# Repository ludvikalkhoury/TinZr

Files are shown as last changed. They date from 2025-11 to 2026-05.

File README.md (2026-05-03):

# TinZr ESP32-C3 Arduino Board Manager Package

This repository contains the **TinZr**, an ESP32-C3-based custom board definition for the Arduino IDE.  
It provides a clean, Boards-Manager-installable package so anyone can use your board with one simple URL.

## Publication Status
The manuscript describing this work is currently under peer review.
The materials in this repository correspond to the submitted version of the work.
Please refrain from redistributing or reproducing this work until the peer-review process is complete.
In the meantime, the preprint is available on SSRN: https://ssrn.com/abstract=6380099, and is also included in this repository (`TinZr_PrePrint_2026-03-30.pdf`). 

If you use this work, please cite:
> **Alkhoury, Ludvik** and Moore, Tony and Swissler, Petras and Hill, Jeremy and Shah, Sudhin A. and Kam, Moshe, TinZr: A Compact Wireless ESP32-C3 Platform for Multi-modal Physiological Data Acquisition (January 01, 2026). Available at SSRN: http://dx.doi.org/10.2139/ssrn.6380099 

---
## Pinout
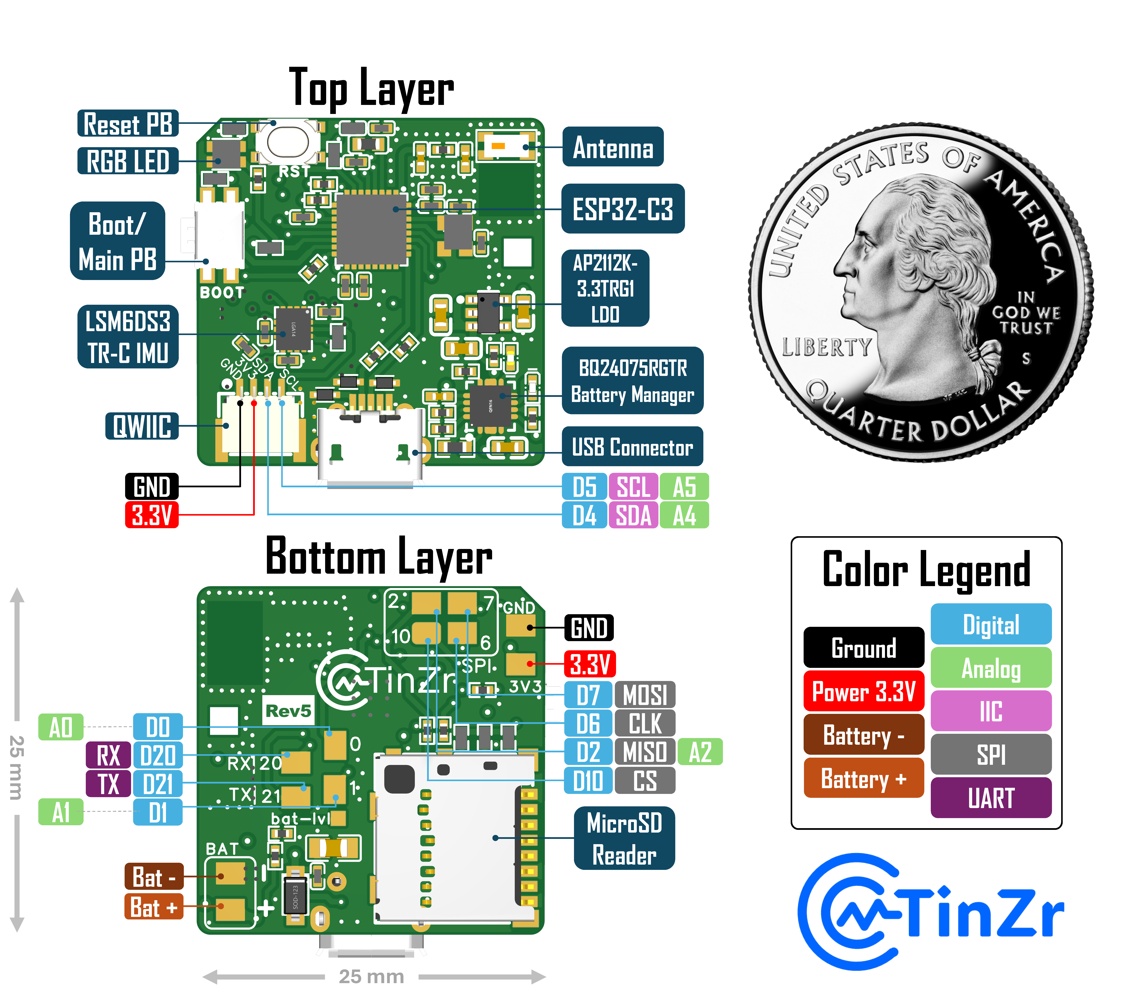
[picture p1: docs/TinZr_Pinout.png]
TinZr ESP32-C3 Pinout


## 🚀 Quick Install

### 1️⃣ Install Espressif ESP32
Open the Arduino IDE and go to:
- Go to **Tools → Board → Boards Manager**
- Find ``esp32 by Espressif Systems``
- Install *only* version `3.3.4`

**⚠️ IMPORTANT: This project is tested and supported exclusively with ESP32 core version `3.3.4`.**  
**Do NOT use any other version — builds may fail or behave incorrectly.**

### 2️⃣ Add the Boards Manager URL
Open the Arduino IDE and go to:

**File → Preferences → Additional Boards Manager URLs**, then paste:

```
https://ludvikalkhoury.github.io/TinZr/package_tinzr_index.json
```

Click **OK**.

### 3️⃣ Install the board package
In Arduino IDE:
- Go to **Tools → Board → Boards Manager**
- Search for **TinZr**
- Click **Install**

### 4️⃣ Select your board
Go to:

**Tools → Board → TinZr Boards → TinZr ESP32-C3 Rev5**

### 5️⃣ Install `TinZrConnect` as a Zipped Arduino Library
#### A) Create the ZIP (IMPORTANT: zip the *library folder*, not the whole TinZr repo)
- Navigate to the `libraries` directory. There you will find the `TinZrConnect` folder (the one that contains `library.properties`).
- Create a zipped version of the `TinZrConnect` folder, and name it `TinZrConnect.zip`.

#### B) Install the ZIP in Arduino IDE
1. In Arduino IDE, go to:
   - **Sketch → Include Library → Add .ZIP Library…**
2. Select `TinZrConnect.zip`
3. Wait for the confirmation message (bottom status bar).

#### C) Verify Installation
1. Go to:
   - **File → Examples**
2. Scroll to find:
   - **TinZrConnect**
3. Open an example sketch and compile.

If you see the examples and the sketch compiles, the library is installed correctly ✅

## 💡 Example Sketch (NeoPixel Test)

```cpp
#include <Arduino.h>
#include "TinZrCore.h" // this library declares TinZrCore TinZr
#include "TinZrLED.h"  // this library declares TinZrStatusLED TinZrLED

void setup() {
    TinZr.begin(25); //LED brightness is 25
}

void loop() {
    TinZrLED.setColor(255,0,0); delay(500);
    TinZrLED.setColor(0,255,0); delay(500);
    TinZrLED.setColor(0,0,255); delay(500);
}
```

#

Copyright © 2026 Ludvik Alkhoury

This software is licensed under the GNU General Public License v3.0.
Commercial licensing options are available upon request.

OSHW Facts

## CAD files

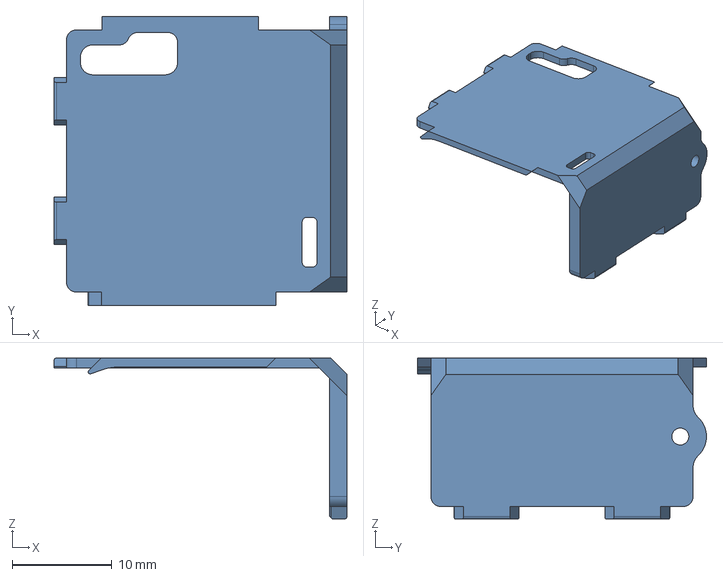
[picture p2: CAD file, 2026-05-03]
3D_designs/TinZrWearableEnclosure - Lid.step
29.4 x 29.0 x 16.2 mm

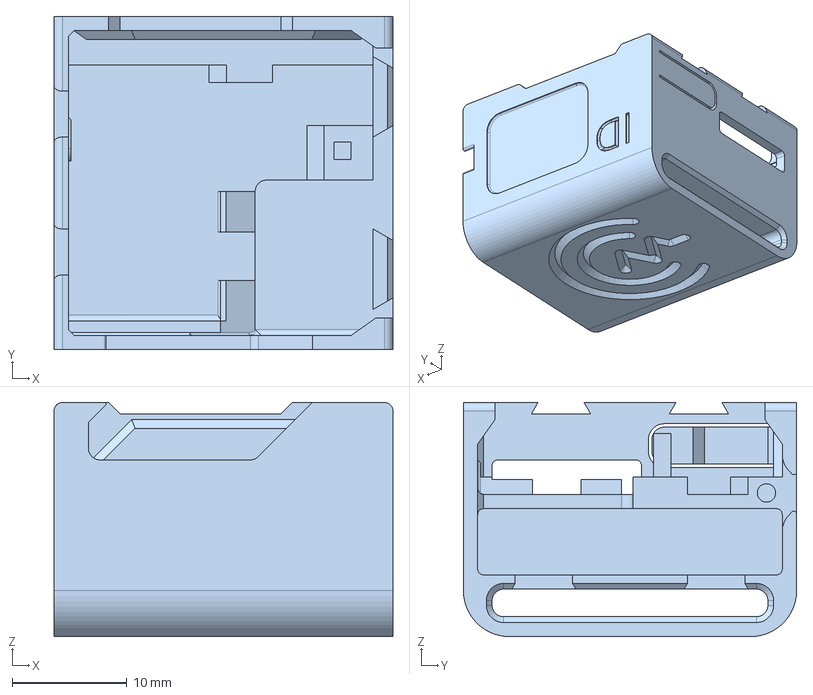
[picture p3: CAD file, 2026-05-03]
3D_designs/TinZrWearableEnclosure - Body.step
29.5 x 29.0 x 20.4 mm

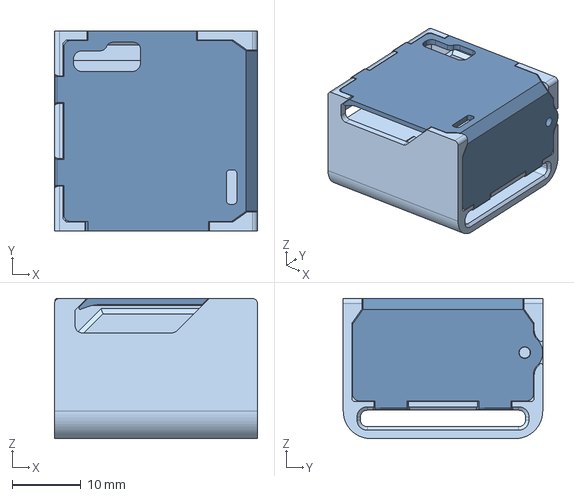
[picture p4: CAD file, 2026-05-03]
3D_designs/TinZrWearableEnclosure.step
29.5 x 29.0 x 20.4 mm

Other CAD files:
3D_designs/TinZrWearableEnclosure - Body.stl
3D_designs/TinZrWearableEnclosure - Lid.stl

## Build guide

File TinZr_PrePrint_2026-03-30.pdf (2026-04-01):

# PREPRINT

PRE-PRINT – this manuscript has not undergone peer review. It is provided for reading and discussion purposes only.

© 2026 Ludvik Alkhoury. All rights reserved. This preprint is made available on arXiv under the arXiv.org perpetual, non-exclusive license.

Article title
TinZr: A Compact Wireless ESP32-C3 Platform for Multi-modal Physiological Data Acquisition.

Authors
Ludvik Alkhoury ¹,∗
, Tony Moore ²

, Petras Swissler ³

, N. Jeremy Hill ⁴,5
, Sudhin A. Shah ¹

, and Moshe Kam⁶,∗

Affiliations
1 Department of Radiology, Weill Cornell Medicine, New York, NY, 10065 USA
2 Mortronics Limited, Folkstown, Balbriggan, Dublin, Ireland
3 Mechanical Engineering Department, New Jersey Institute of Technology, Newark, NJ, USA
4 National Center for Adaptive Neurotechnologies, Stratton VA Medical Center, Albany, NY, USA
5 Electrical and Computer Engineering Department, State University of New York at Albany, NY, USA
6 Electrical and Computer Engineering Department, New Jersey Institute of Technology, Newark, NJ, USA Corresponding authors email addresses
∗Ludvik.alkhoury@gmail.com and Kam@njit.edu

Abstract
Microcontrollers have become central to wearable technologies. As these systems continue to evolve, both form factor and functional integration have become critical design considerations. In this study, we present TinZr, a compact, wireless, and open-source controller based on the ESP32-C3 microcontroller. The TinZr integrates an inertial measurement unit (IMU), an onboard battery management circuit, Wi-Fi and Bluetooth Low Energy, a microSD card reader, and multiple GPIOs supporting digital, analog, I²C, SPI, and UART interfaces. The complete system measures only 25 mm × 25 mm, making it well-suited for wearable applications. All production files, including PCB design, firmware, and a 3D model of a wearable enclosure, are publicly available. Two primary use cases for TinZr are demonstrated: (a) multi-device communication and coordination, and (b) wireless IMU data acquisition. The TinZr supports both real-time data streaming via Wi-Fi/BLE and local logging to a microSD card. Local streaming makes the TinZr suitable for extended research experiments and field studies where continuous wireless connectivity may not be available. An accompanying Arduino library, TinZrConnect, is provided to facilitate programming and integration with existing systems. Overall, the combination of compact design, wireless flexibility, and open-source accessibility, makes TinZr a versatile solution for various sensing applications.

Keywords
Microcontroller, ESP32-C3, Wearable Devices, Physiological Signals, Physiological Monitoring, Data Acquisition, Multimodal Signals, Wireless Communication, Multi-Device Synchronization, Open-Source Hardware, Signal Processing, Inertial Measurement Unit (IMU), Low-Power Design, MicroSD Data Logging, Battery-Powered Systems

# PREPRINT

### 1. Specifications table

Hardware name | TinZr
Subject area | • Electrical and biomedical engineering • Neuroscience • Swarm robotics • Educational tools and open source alternatives to existing infrastructure
Hardware type | • Measuring physical properties and in-lab sensors • Field measurements and sensors • Electrical and biomedical engineering • Multi-functional microcontroller platform • Compact and wearable embedded controller • Wireless data acquisition and communication system (Wi-Fi / BLE) • Real-time signal processing • Physiological signal acquisition and sensor interfacing (ECG, PPG, IMU) • Supports digital communication protocols (I²C, SPI, UART, GPIO)
Closest commercial analog | • Seeed XIAO ESP32-C3 • ESP32-C3 Mini • DFRobot Beetle ESP32-C6 • Adafruit GEMMA v2 • Teensy 4.1
Open source license | CERN Open Hardware Licence (OHL) v2.0 Permissive
Cost of hardware | $65 (including shipping and customs duties)
Source file repository | https://osf.io/hx4cm/
OSHWA certification UID | US002796

# PREPRINT

### 2. Hardware in context

Wearable sensing platforms are gaining popularity for their ability to deliver non-invasive, continuous health insights to athletes, patients, and everyday users – while evolving to incorporate sophisticated on-device sensors and analytics. The global wearable sensors market was valued in 2024 at USD 1.4 billion and is projected to grow to USD 6.3 billion by 2033, at a compound annual growth rate (CAGR) of 18.3% over 2025–2033 [1, 2]. This surge is largely driven by growing demand for telehealth, long-term monitoring, real-time health tracking, and military applications.
Physiological signal monitoring has become increasingly widespread, with wearable systems now employed by athletes, patients, soldiers, and everyday users to enable continuous health and performance tracking [3, 4, 5, 6]. Consequently, many everyday wearables (e.g., watches) now go beyond basic functionality by including onboard sensing hardware, such as accelerometers for activity and motion tracking [7]; photoplethysmography (PPG) sensors for heart rate [8] and oxygen saturation calculation [9]; electrocardiography (ECG) sensors for cardiac rhythm monitoring [10]; temperature sensors for body or skin thermal profiling [11]; and even biochemical sensors for measuring variables like glucose [12], for richer health and activity monitoring [4, 13].
Wearable systems for physiological monitoring increasingly depend on microcontroller units (MCU) and platforms that provide tight integration, compact form factors, and support for multi-modal sensing. The continued miniaturization and increasing computational capability of modern MCUs have made it possible to embed real-time sensing, processing, and wireless communication within small, battery-powered enclosures. Additionally, such MCUs offer sufficient local processing power, robust data logging, and versatile interfaces for auxiliary modules such as inertial, optical, and electrophysiological sensors.
Several open hardware and research platforms have emerged to address these challenges. For instance, Cog-Watch [14] is an open-source multi-sensor wrist platform that integrates heart rate, respiration, skin conductance, and temperature sensing, to study physiological and behavioral responses in daily activities. CogWatch uses the Adafruit QT Py ESP32-S2 MCU [15] for data acquisition and measures around 29 mm x 38 mm (just the PCB without any sensor enclosures). H-Watch [16] extends these capabilities into a wristwatch-like platform that incorporates multiple radios and energy harvesting, maintaining ultra-low power consumption for long-term wearable deployment. The main purpose of H-Watch is early COVID-19 detection. BioGAP-Ultra
[17] is a modular edge-AI platform that supports synchronized acquisition of EEG, EMG, ECG, and PPG signals with on-device processing and flexible form factors. The BioGAP-Ultra firmware runs on the nRF5340 SoC using the Zephyr RTOS, and the accompanying Android software suite enables background data reception, real-time visualization, some parameter configuration, and data storage. Finally, the Multi-Sensor Wearable Health Device (MWHD) framework [18] uses the CC2640R2F Cortex®-M3 [19] MCU for real-time heart rate and peripheral oxygen saturation (SpO2) monitoring from PPG signals, temperature, and motion, coupled with wireless data transmission and mobile application feedback. Together, these platforms illustrate the stateof-the-art in wearable microcontroller integration, where the convergence of low-power embedded processing, miniaturization, and open hardware design has enabled compact, reconfigurable, and affordable solutions for physiological signal monitoring.
Some of the above-mentioned platforms demand significant expertise to program or extend at the driver and firmware level. However, there are compact and flexible MCUs that can be easily programmed via the Arduino ecosystem – making them highly accessible for rapid prototyping, research deployments, and wearable device development. For example, we list several widely used controllers such as Seeed XIAO ESP32-C3 [20], DORHEA ESP32-C3 Mini [21], DFRobot Beetle ESP32-C6 [22], Adafruit GEMMA v2 [23], and PJRC Teensy 4.1 [24]. In general, most of these controllers are compact and thus suitable for wearable applications. The Seeed XIAO ESP32-C3 is very compact and offers Wi-Fi/BLE connectivity with onboard battery management, though it lacks a microSD card reader and has limited header accessibility. The DORHEA ESP32-C3 Mini does not include battery management or an SD card interface. The DFRobot Beetle ESP32-C6 similarly lacks an SD card reader and accessible headers. The Adafruit GEMMA v2 is extremely small and lightweight but does not include a charging unit, SD card reader, and expansion headers. The PJRC Teensy 4.1 includes an SD card reader, making it well-suited for data logging, but it lacks Wi-Fi/BLE and is physically bulkier than the other options.
In this study, we introduce the TinZr, which builds on existing designs by providing a fully wireless con-

# PREPRINT

troller in a compact 25 mm × 25 mm form factor, combining sensing, data logging, and communication in a minimal open-source package. It uses the ESP32-C3 MCU and integrates an inertial measurement unit (IMU) comprising a 3-axis accelerometer and 3-axis gyroscope, battery management circuitry, Wi-Fi and BLE 5.0 connectivity, a microSD card reader, and GPIOs supporting digital, analog, I²C (it provides an on-board QWIIC connector), SPI, and UART. A detailed specification comparison between the commercially available controllers and the TinZr is available in Table 1. Importantly, the TinZr can be programmed via the Arduino ecosystem, lowering the barrier to use. This functional density enables multimodal physiological signal acquisition, on-device processing, and flexible data handling (streaming or local logging). All production files for the TinZr, including PCB designs and 3D enclosure models for wearables applications, are publicly available at https://osf.io/hx4cm/. The onboard microSD reader supports long-duration, high-resolution logging, essential for field or extended experiments where continuous wireless transmission may not be feasible. Wireless connectivity via Wi-Fi and BLE remains available when real-time streaming is needed. We provide an accompanying Arduino library, TinZrConnect, to facilitate programming and integration of TinZr with existing systems. Overall, TinZr offers a low-cost, power-efficient, and compact alternative that surpasses lighter platforms by combining local storage, wireless flexibility, and standardized sensor interfacing in a single module.

| Seeed XIAO ESP32-C3 [20] | DORHEA ESP32-C3 Mini [21] | DFRobot Beetle ESP32-C6 [22] | Adafruit GEMMA v2 [23] | PJRC Teensy 4.1 [24] | TinZr
Dimensions (mm) | 21 x 17.8 | 22 x 18 | 25 x 20 | 28 (diameter) | 61 x 18 | 25 x 25
Nbr. GPIOs | 11 | 11 | 13 | 3 | 55 | 10
Nbr. Analog Pins | 4 | 4 | 7 | 1 | 18 | 5
Nbr. Digital Pins | 11 | 11 | 13 | 3 | 55 | 10
2C I | Yes | Yes | Yes | Yes | Yes | Yes
SPI | Yes | Yes | Yes | Yes | Yes | Yes
UART | Yes | Yes | Yes | No | Yes | Yes
On-board Mi-croSD Card Reader | No | No | No | No | Yes | Yes
On-board Bat-tery Management | Yes | No | Yes | No | No | Yes
On-board QWIIC Connector | No | No | No | No | No | Yes
On-board IMU | No | No | No | No | No | Yes
On-board Con-trollable RGB LED | No | No | No | No | Yes | Yes
On-board Push Button | Yes (Reset & Boot) | Yes (Reset & Boot) | Yes (Reset & Boot) | Yes (Reset) | Yes | Yes (Reset & Boot/Control)
Unit Price (in USD) (January, 2026) | ∼ $5 − 10 | ∼ $8 − 12 | ∼ $7 − 10 | ∼ $9.95 | ∼ $30 − 50 | ∼ $65

Table 1: Features and price comparison between some commercially available controllers and TinZr in terms of dimensions, GPIOs, interfaces, and price.

### 3. Hardware description

Our repository, available at https://osf.io/hx4cm/, provides the following materials:

- raw and editable schematics and PCB layout files used in the design of the TinZr ESP32-C3 Rev5 ; PCB layouts are provided in .eprj format for EasyEDA Pro [25], as well as in .kicad pcb/.kicad sch format for KiCad [26];

- a 3D model of the wearable enclosure, designed to house the TinZr device and battery, provided in .step format and compatible with FreeCAD [27] and other CAD software;
- exported manufacturing files, including Gerber files, pick-and-place data, and bills of materials (BOM) for the PCBs, as well as .stl files for 3D printing the wearable enclosure.

Figure 1 illustrates the TinZr pinout along with the top and bottom layers of the PCB. Figure 2 shows the 3D model of the wearable TinZr enclosure, illustrating the exploded and assembled views used to house the PCB and battery. The major functional blocks and embedded components of the system are described in the

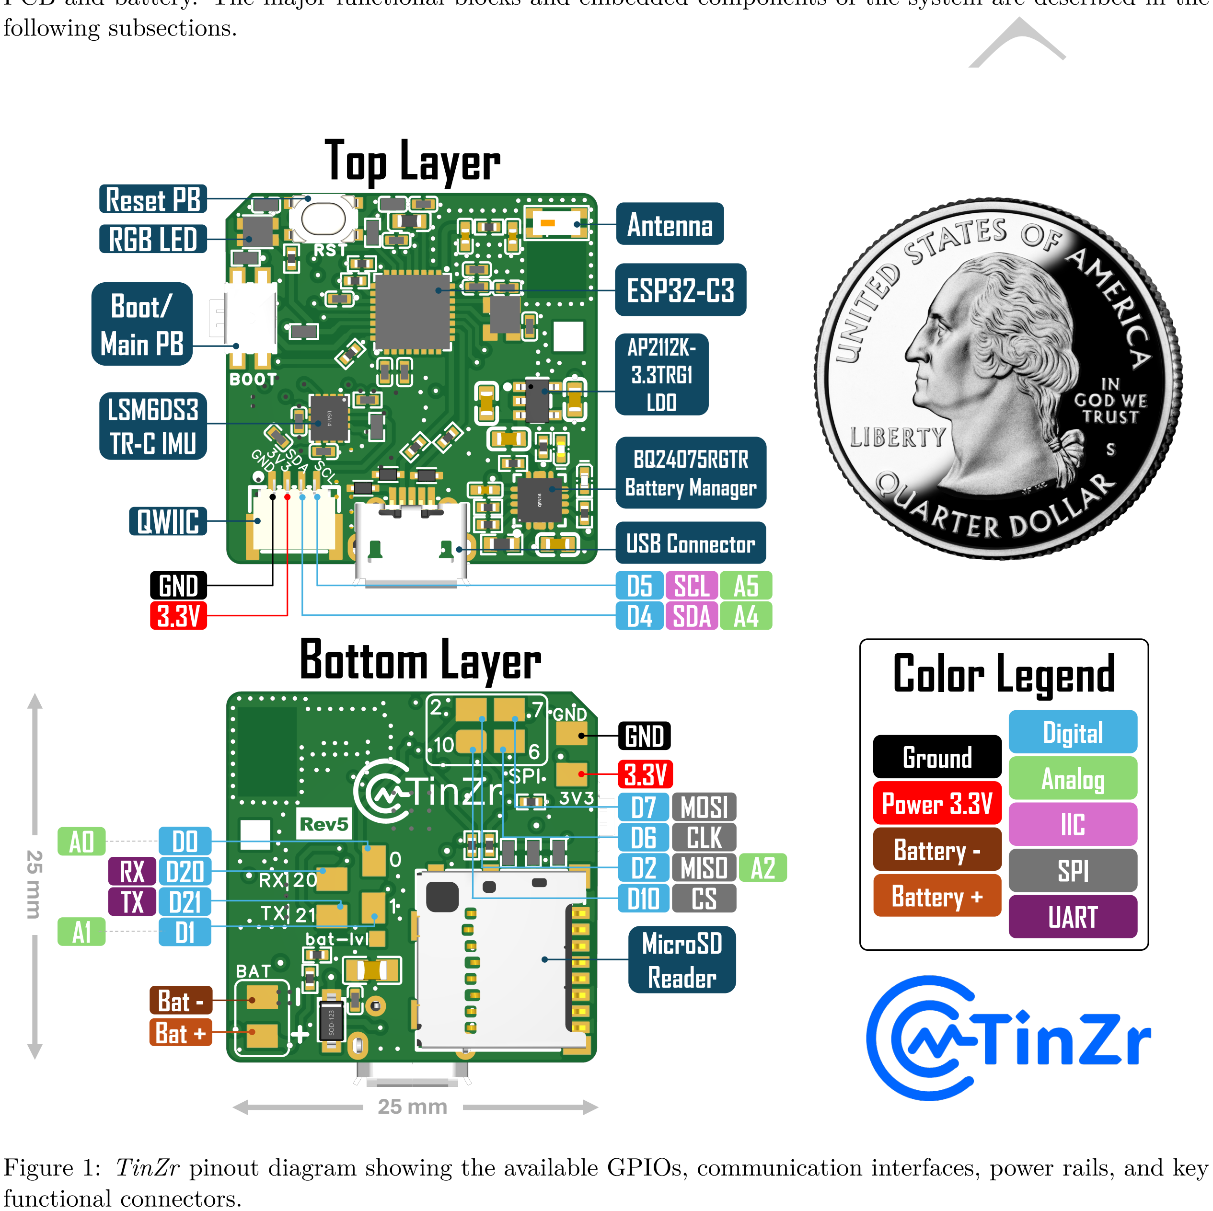
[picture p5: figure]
PREPRINT following subsections.; Top Layer; GND 3.3V; MicroSD Reader; Bat - Bat +; BQ24075RGTR Battery Manager; AP2112K- 3.3TRG1 LDO; ESP32-C3; Antenna; USB Connector QWIIC; LSM6DS3 TR-C IMU; Boot/ Main PB; RGB LED; Reset PB; GND; SDA; SCL; CLK; MOSI; MISO A2; Color Legend; Digital Ground; Power 3.3V; IIC; UART; SPI; Analog; Battery - Battery +; Bottom Layer; functional connectors.

Figure 1: TinZr pinout diagram showing the available GPIOs, communication interfaces, power rails, and key

3.1 ESP32-C3 Development Board

The central component of the TinZr is an ESP32-C3-based microcontroller module, labeled “ESP32-C3” in Figure 1. The ESP32-C3 module integrates a single-core RISC-V processor with native 2.4 GHz Wi-Fi and

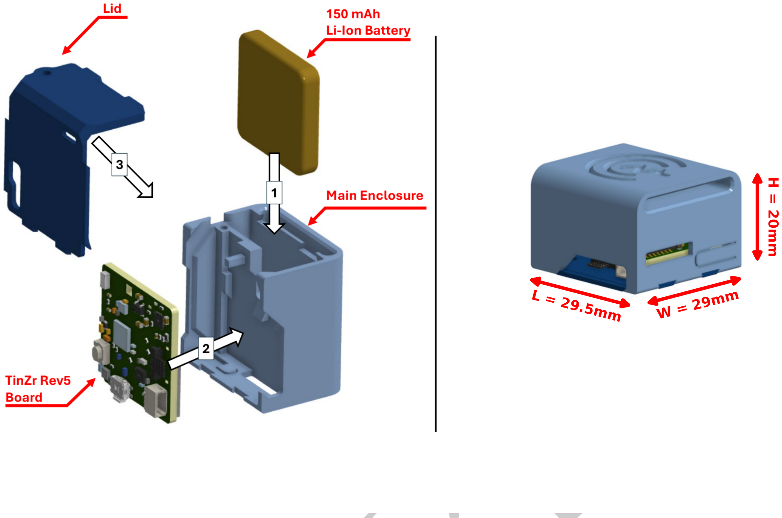
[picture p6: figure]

# PREPRINT

Figure 2: 3D model of the TinZr wearable enclosure illustrating the mechanical design used to enclose the PCB and battery for wearable applications. The exploded view (left panel) shows the individual enclosure components, including the main enclosure, top lid, battery lid, TinZr Rev 5 PCB, and 150 mAh Li-ion battery, while the assembled view (right panel) shows the fully assembled enclosure (length=29.5mm, width=29mm, and height=20mm). Dashed orange arrows in the exploded view indicate the assembly directions and relative placement of each component during enclosure assembly.

Bluetooth Low Energy (BLE) connectivity, providing a compact and power-efficient solution well suited for wearable and portable applications. The processor operates at clock frequencies of up to 160 MHz, offering sufficient computational performance for real-time control, synchronization, and wireless communication tasks. The ESP32-C3 module provides a sufficient number of general-purpose input/output (GPIO) pins to support the required digital and analog interfaces, including I²C, SPI, and UART communication buses, while maintaining low power consumption during both active operation and deep sleep modes. Although the ESP32-C3 module offers fewer GPIOs than larger development boards such as the Teensy 4.1, the pin allocation in TinZr was carefully designed to prioritize the interfaces and peripherals most relevant to biosignal synchronization, wearable sensing, and wireless data transfer. As a result, all core system functionalities are supported without reliance on external multiplexing or expansion hardware.
The ESP32-C3 module is positioned centrally on the TinZr PCB, with its USB interface accessible at the board edge to facilitate firmware development, debugging, and power delivery (Figure 1).
Overall, the ESP32-C3 module provides a compact, wireless, and power-efficient computational core that enables TinZr’s functionality while supporting scalable, open-hardware development.

3.2 Inertial Measurement Unit (IMU)

Motion sensing in the TinZr platform is provided by an STMicroelectronics LSM6DS3TR-C inertial measurement unit (IMU), labeled “LSM6DS3” in Figure 1. The LSM6DS3TR-C unit integrates a 3-axis accelerometer and a 3-axis gyroscope in a compact, low-power package, enabling continuous monitoring of linear acceleration and angular velocity.
The accelerometer supports selectable full-scale ranges up to ±16 g, while the gyroscope supports angular

# PREPRINT

rate measurements up to ±2000 dps, allowing the device to capture both fine-grained motion and high-dynamic activities. The IMU supports output data rates up to several kilohertz and communicates with the ESP32-C3 module via the I²C bus, providing reliable and low-latency motion data acquisition.
The LSM6DS3TR-C unit was selected for its low power consumption, small footprint, and proven reliability in wearable and embedded applications. In the context of TinZr, IMU data can be used to support motionaware sensing, artifact detection, and synchronization tasks, particularly in mobile and wearable experimental settings.

3.3 Battery Management and Power Regulation

Power management in the TinZr platform is handled by a Texas Instruments BQ24075RGTR battery management integrated circuit, labeled “BQ24075” in Figure 1. The BQ24075RGTR unit is a single-cell lithiumion/lithium-polymer (Li-ion/Li-Po) charger with integrated power-path management, enabling simultaneous battery charging and system operation.
The device supports USB-compatible input sources and provides regulated power to the system while safely managing battery charging, including preconditioning, constant-current, and constant-voltage charging phases. Integrated safety features, such as thermal regulation, overvoltage protection, and charge termination, ensure reliable and safe operation in wearable and portable applications.
Power-path management allows TinZr to operate directly from an external power source when available, while automatically switching to battery power when disconnected, without interrupting system operation. This capability is particularly important for long-duration experiments and mobile use cases, where uninterrupted operation and safe battery handling are critical. The BQ24075RGTR unit was selected for its compact footprint, low external component count, and proven reliability in battery-powered embedded systems.
The charging behavior of the BQ24075RGTR unit in TinZr is configured using three external resistors connected to the “ISET”, “ILIM”, and “TMR” pins. The fast-charge current is set by a resistor on the “ISET” pin. With an 8.2 kΩ resistor, the resulting charge current is approximately 100 mA, which is well matched to the 150 mAh single-cell lithium-polymer battery [28] used with the TinZr and corresponds to a charge rate of approximately 0.7C.
The maximum input current drawn from the external power source is limited via the “ILIM” pin to ensure compatibility with USB power supplies while supporting simultaneous system operation and battery charging. With a 3 kΩ resistor connected to “ILIM”, the input current is limited to approximately 520 mA, providing sufficient headroom for system operation while remaining within typical USB power constraints.
In addition, a resistor connected to the “TMR” pin sets the safety timeout for the charging process. With a 46.4 kΩ resistor, the precharge safety timer is approximately 37 minutes, and the fast-charge safety timeout is approximately 6.2 hours, providing protection against abnormal charging conditions. These resistor values were selected specifically for the 150 mAh battery [28] used with the TinZr, and can be adjusted (by desoldering the onboard resistors and replacing them with desired ones) to accommodate larger-capacity batteries by increasing the allowable charge and input currents, while maintaining manufacturer-recommended charge rates and thermal limits.
The battery is soldered directly to the rear side of the PCB at the pads labeled (+) and (-), ensuring correct polarity and compact mechanical assembly.

3.4 On-board Controllable RGB LED

TinZr includes an addressable RGB status LED (“NeoPixel”-class), labeled “RGB LED” in Figure 1. This type of LED integrates red, green, and blue emitters together with a small control driver in a single package, allowing the LED color and brightness to be digitally controlled from a single microcontroller GPIO pin.
The RGB LED can be programmed to provide a visual indication of device state during development and deployment (e.g., BLE advertising/connection state, recording status, or error conditions). Since the LED can draw non-negligible current at high brightness, TinZr firmware limits brightness and disables the LED during low-power operation when appropriate. This feature preserves battery life while retaining a simple, user-facing diagnostic interface.

# PREPRINT

The RGB LED is a fully software-controllable indicator intended for general system feedback and debugging. TinZr also includes dedicated power and charging LEDs that operate independently of firmware and provide continuous hardware-level indication of battery and charging status.

3.5 MicroSD Card Interface

Local data storage in the TinZr platform is provided by an on-board microSD card reader, labeled “microSD Reader” in Figure 1. The microSD interface allows sensor data, timestamps, and system logs to be stored directly on removable flash media, enabling fully standalone operation without reliance on a continuous wireless connection.
The microSD card communicates with the ESP32-C3 module via the SPI bus, providing a simple and widely supported interface for embedded systems. This design choice ensures broad compatibility with standard microSD cards and commonly used embedded file systems, while maintaining predictable timing and resource usage. The SPI-based implementation also simplifies integration alongside other peripherals on the shared communication bus.
The inclusion of local storage is particularly important for long-duration recordings, field deployments, and wearable experiments where wireless bandwidth or connectivity may be limited or unavailable. By offloading data logging to the microSD card, TinZr supports reliable data capture with minimal impact on wireless performance and power consumption. We validated data logging using a 32 GB microSDHC card (Silicon Power Elite, FAT32-formatted).

3.6 QWIIC Connector

The TinZr platform includes an on-board QWIIC-compatible expansion connector, labeled “QWIIC” in Figure 1, providing a standardized interface for external peripheral integration. The QWIIC connector exposes the I

2C bus along with power and ground, enabling rapid connection of compatible sensors and modules without soldering.
By leveraging the I²C interface, the QWIIC connector allows additional devices – such as environmental sensors, auxiliary motion sensors, or other low-power peripherals – to be easily integrated into the system. This design supports modular expansion while minimizing wiring complexity and reducing the risk of incorrect connections during prototyping or deployment.
The inclusion of a QWIIC connector enhances the flexibility of the TinZr platform by enabling rapid hardware extensions without modifying the core PCB design. This feature is particularly useful for experimental and research-oriented applications, where sensor configurations may evolve over time or vary between deployments.

3.7 Reset and User Push Buttons

TinZr includes two on-board push buttons: a dedicated reset button, labeled “Reset PB”, and a multifunction push button, labeled “Boot/Main PB” in Figure 1. The reset button provides a hardware reset of the ESP32-C3 module, allowing the system to be restarted without cycling power during development or troubleshooting. The main PB button serves a dual purpose. When used in conjunction with the reset sequence, it can be used to place the ESP32-C3 module into bootloader mode for firmware flashing. During normal operation, the same button can be repurposed by the firmware as a general user input, enabling application-specific functionality such as mode selection, event marking, or user interaction.
The main PB is implemented as right-angle (90◦
) tactile switch. This orientation allows the button to be actuated from the side of the enclosure rather than the top surface of the PCB, simplifying mechanical integration and improving usability in compact enclosures. The right-angle design is particularly advantageous for wearable applications, where low profile, accessibility, and protection against accidental presses are important considerations.

3.8 Micro-USB Connector

The TinZr platform includes a micro-USB connector, labeled “USB Connector” in Figure 1. It provides both power input and a wired communication interface to the ESP32-C3 module. This connector is used for

# PREPRINT

battery charging via the on-board power management circuitry as well as for firmware flashing, debugging, and development during device configuration.
When connected to an external power source, the micro-USB interface supplies power to the system and enables charging of the on-board lithium-polymer battery through the BQ24075 battery management IC. During development, the same interface allows firmware to be uploaded to the ESP32-C3 module and supports serial communication for debugging and status monitoring.
The micro-USB connector was selected for its compact form factor, mechanical robustness, and wide availability of cables, making it well suited for both early-stage development and enclosed wearable applications. Its placement at the edge of the PCB facilitates straightforward access when the device is integrated into a protective enclosure.

### 4. Design files summary

Design file-name | File type | License | Location of the file
TinZr Rev 5 PCB | raw schematics, *.svg & *.kicad sch; PCB sketches, *.kicad pcb; EasyEDA Pro source, *.eprj; manufacturing files, *.grb & *.csv | CERN OHL-P 2.0 | https://osf.io/hx4cm/
Enclosure 3D de-signs | source, *.step; manufacturing, *.stl | CERN OHL-P 2.0 | https://osf.io/hx4cm/
BOM of all com-ponents | *.csv | CERN OHL-P 2.0 | https://osf.io/hx4cm/
Firmware code | Arduino IDE source, *.ino; Python-based GUIs, *.py | GNU General Pub-lic License, version 3 (GPLv3) | https://github.com/ludvikalkhoury/TinZr.git
- TinZr Rev5 PCBs: design files of TinZr Rev5 PCB are available. These are the raw and editable EasyEDA Pro files (.eprj format) as well as KiCAD PCB files (.kicad pcb format). Also available are manufacturing files that can be used directly to produce the PCBs. These are Gerber (.grb), pick and place (.csv), and bill of materials (BOM) (.csv) files.
- Enclosure 3D designs: raw editable 3D design files (in .step format) are available for the TinZr’s wearable enclosure. Also are available the corresponding .stl files that can be used directly in slicing software to generate a g-code for a 3D printer.
- BOM of all components: a BOM is available that contains all the components we used to build the TinZr Rev5 PCB.
- Firmware code: an Arduino library, TinZrConnect, is available, with examples that can be directly updated and run on the TinZr.

### 5. Bill of materials (BOM)

We provide a detailed and comprehensive BOM in the TinZr’s OSF repository https://osf.io/hx4cm/, listing all electronic components along with their part numbers, manufacturers, and supplier IDs.
The cost of making the TinZr Rev5 is around $65 per unit. This per-unit cost assumes a minimum quantity of 5, reflecting the minimum quantity required by the PCB manufacturing company, and include shipping and current customs duties (December 2025).

# PREPRINT

### 6. Build instructions

Step-by-step instructions are provided, on how to manufacture the TinZr.

6.1 PCB Manufacturing

As previously mentioned, all the files needed in the PCB manufacturing process are publicly available. These files are Gerber, Pick-and-Place, and BOM, and they can be found in the OSF repository, https://osf.io/hx4cm/. We have used JLCPCB (https://jlcpcb.com/)¹
to manufacture the boards since it provides a wide variety of base materials and colors and other PCB specifications. We designed and built the TinZr Rev 5 as a 4-layer PCB, using a standard quality PCB with flame retardant (FR-4) as the base material. We picked a PCB thickness of 1.6 mm with a hot air solder leveling (HASL) (with lead) surface finish. We also chose the copper weight on the top and bottom to be 1 oz/ft²
. We used two ground planes (top and bottom).

6.2 Wearable Enclosure 3D Printing

We provide a 3D model (.stl files) for an enclosure designed to fit the TinZr Rev5’s PCB as well as a 150 mAh battery that power the TinZr.
The wearable enclosure was printed using a local Creality Ender-3 3D printer (Fused Deposition Modeling (FDM)), using PLA filaments. The quality of the print was acceptable for our purposes. In case the user requires a higher resolution, we suggest using a higher quality alternatives such as Multi-Jet Fusion (MJF) printing, which could result in a higher-quality product (but comes at a higher price).

6.3 Component Soldering

For our design, we used the mounting and soldering services provided by JLCPCB to assemble and solder all components on the TinZr board. The only exception was the main push button, which was not available through JLCPCB at the time of ordering and was therefore soldered manually.

6.4 Assembly

The TinZr Rev 5 is fully functional out-of-the-box and does not require any assembly for basic operation. However, when integrating the system into a wearable enclosure, the following steps should be followed to properly assemble the wearable unit.

1. Solder the battery positive (+) and negative (–) leads to the corresponding battery terminals located on the bottom side of the TinZr board (Figure 3, Step 1).
2. Insert the battery into the designated battery compartment and place the TinZr board onto its designated mounting platform within the enclosure (Figure 3, Step 2).
3. Clip the snap-fit lid onto the main enclosure to secure the assembly (Figure 3, Step 3). The wearable unit is now fully assembled and ready for use.

The final panel of Figure 3, labeled Full Assembly, shows the completed TinZr Rev 5 wearable unit after all assembly steps have been performed.

TinZr provides a battery-level monitoring feature. Battery voltage is measured via the bat-lvl pad, which must be connected by soldering to the Pin 1 pad (see the bottom layer of Figure 1); this pin is designated in the TinZr firmware as the default battery-sensing input. This connection is required for the battery level to be reported correctly in the example firmware included in the repository.

1Other PCB manufacturers offer comparable services – for example, DKRed (https://www.digikey.com/en/resources/dkred), OSH Park (https://oshpark.com/), and PCB Way (https://www.pcbway.com/), to name a few.

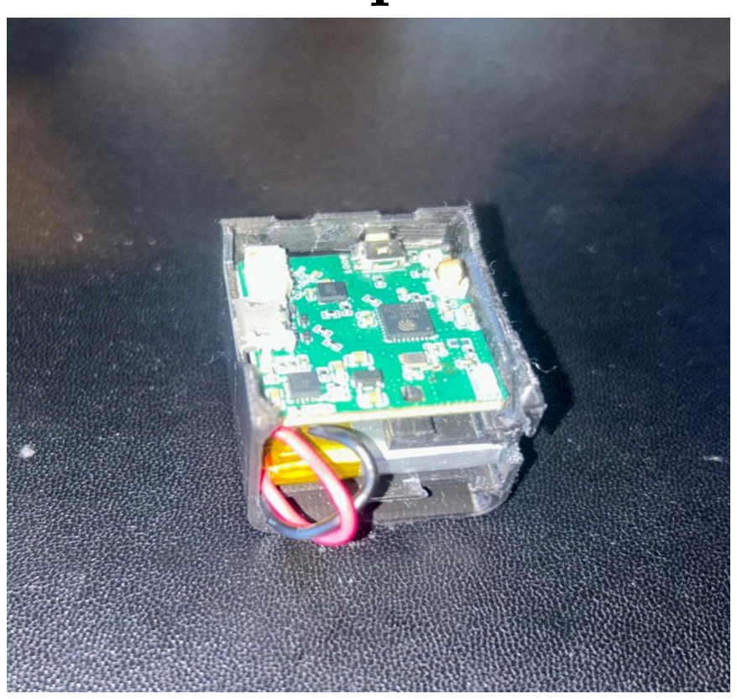
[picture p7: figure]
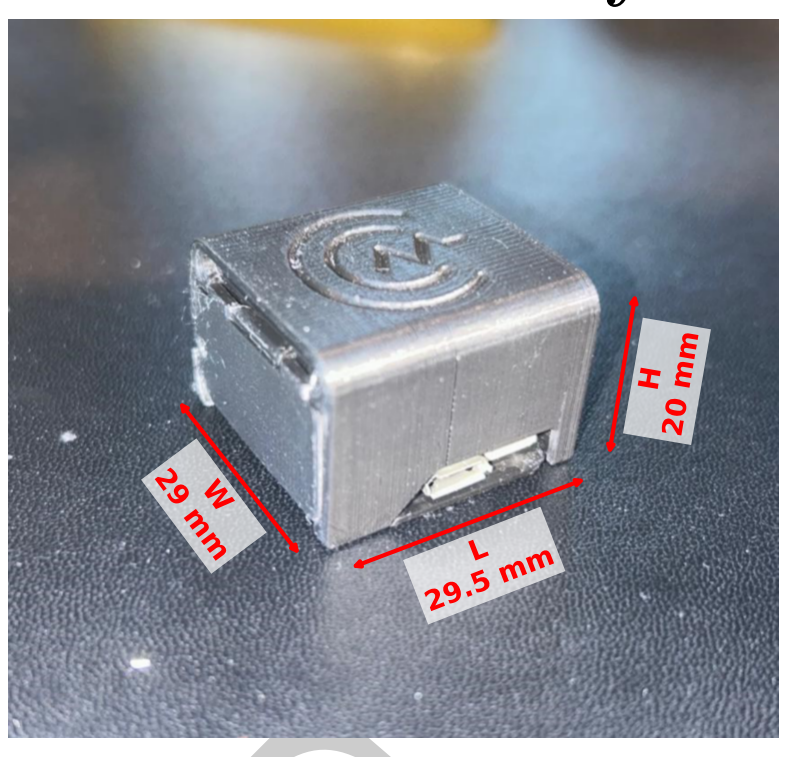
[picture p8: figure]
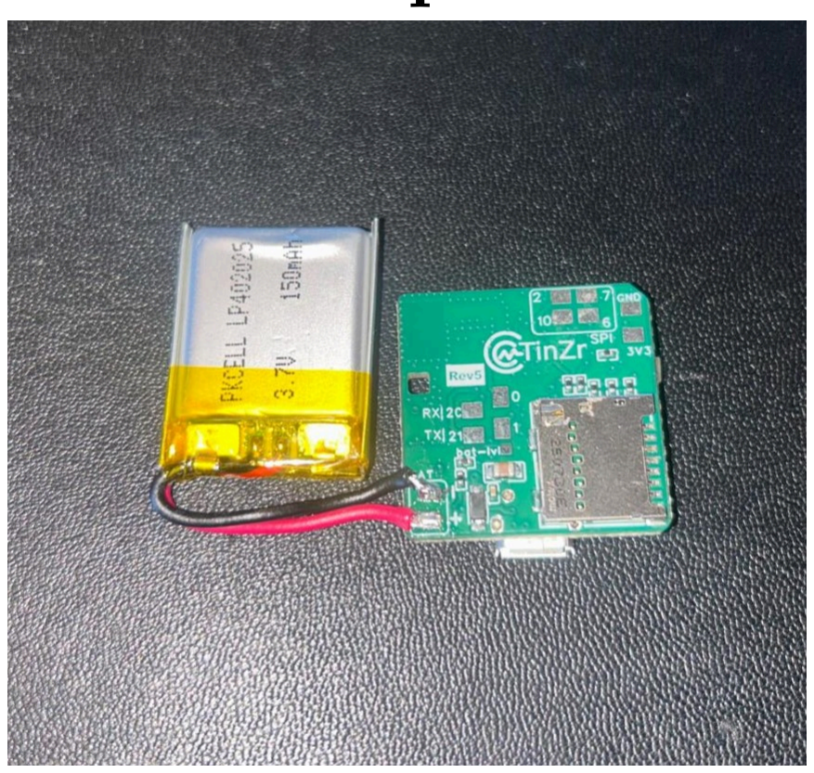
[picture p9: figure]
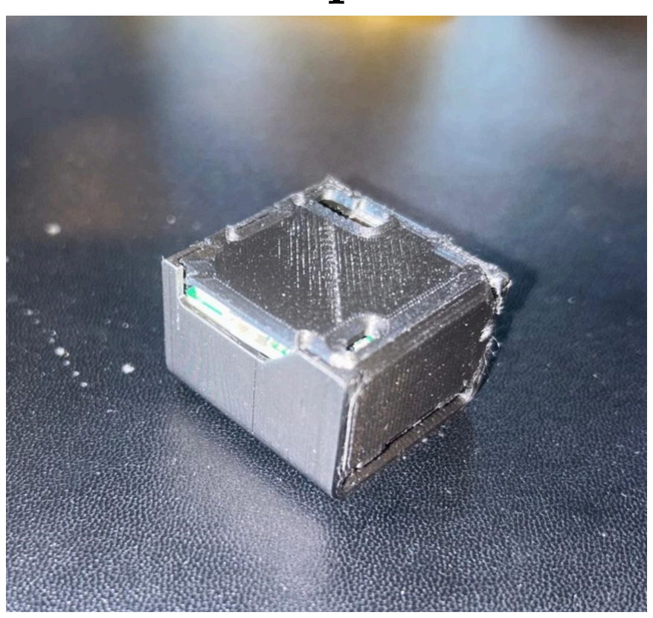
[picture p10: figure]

# PREPRINT

Step 1 | Step 2 | Step 3 | Full Assembly

Figure 3: Step-by-step illustration on how to assemble the TinZr Rev 5 board with the wearable 3D enclosure, following the steps described in Section 6.4. The last panel shows the fully assembled device (length=29.5mm, width=29mm, and height=20mm).

6.5 Programming

The TinZr Arduino library, TinZrConnect, can be downloaded directly from the TinZr GitHub repository https://github.com/ludvikalkhoury/TinZr.git. In addition to the Arduino library, TinZr provides a custom Arduino Board Manager package with full support for the TinZr Rev 5 hardware, enabling seamless installation and configuration within the Arduino IDE. The TinZrConnect library includes a collection of example sketches designed to test and demonstrate the full functionality of the TinZr Rev 5 board.
For instance, the TinZrCore sketch provides a basic demonstration of core hardware features, including the main push button, status LED, and battery level monitoring (assuming the battery-level pad has been soldered to Pin 1 pad as described in Section 6.4).
The TinZrComCenter sketch establishes a centralized communication framework in which multiple TinZr devices connect to a single host system acting as a communication hub. In this architecture, each TinZr operates as an independent node that can transmit data and receive control messages over Wi-Fi. The central hub manages all connected devices and can selectively broadcast commands to all TinZr units or address individual devices independently. This design enables coordinated multi-device operation and is well suited for distributed or swarm-style applications, such as synchronized sensing or collaborative robotics.
Another example, TinZrWearableSD, enables communication between one or more TinZr devices and a central PC over Bluetooth Low Energy (BLE), allowing the PC to control recording start and stop events while enabling local logging of inertial measurement unit (IMU) data (accelerometer and gyroscope) as well as red and infrared photoplethysmographic (PPG) data when a MAX30102 sensor [29] is connected via QWIIC. Both TinZrComCenter and TinZrWearableSD are accompanied by graphical user interfaces (GUIs), along with the underlying Python source code, allowing users to operate the system without requiring extensive experience in firmware or software development. In later sections of this paper, we demonstrate the capabilities of the TinZr Rev 5 using TinZrComCenter and TinZrWearable as representative example use cases.

### 7. Operation instructions

7.1 User Instructions

The TinZr Rev 5 operates similarly to other microcontrollers in the ESP32 family. Here we follow a simple three-step workflow: Power, Program, and Deploy.

1. Power: The TinZr Rev 5 can be powered either by connecting it to a host computer via USB or by using a connected rechargeable battery for standalone or wearable operation. When powered through USB, a white status LED illuminates, indicating that the board is receiving power. When a battery is connected and charging, a green charging-status LED remains illuminated and turns off once charging is complete. When operating solely on battery power, no LEDs are illuminated. The power and charging status LEDs are located to the left of the USB connector at the same vertical level (see Figure 1, top layer).

# PREPRINT

2. Program: The TinZr Rev 5 can be programmed with any ESP32-compatible firmware, including userdeveloped sketches or example programs provided with the TinZrConnect library. Programming is performed using the Arduino IDE after selecting the appropriate board and serial port. In some cases, the board must be placed into bootloader mode manually. This is accomplished by pressing and holding the main button, briefly pressing and releasing the reset button, and then releasing the main button. Once the firmware upload is complete and the program begins execution, the device is ready for use.
3. Deploy: After programming, the TinZr Rev 5 can be deployed either while connected via USB or as a fully standalone device powered by the onboard battery. In deployed operation, the device can stream sensor data, communicate wirelessly using BLE or Wi-Fi, or operate autonomously depending on the loaded firmware. This flexibility allows the TinZr to function both as a development platform and as an embedded wearable system.

7.2 Safety Considerations

The TinZr Rev 5 is a low-voltage, battery- and USB-powered microcontroller platform intended for embedded sensing, wearable prototyping, and wireless data acquisition. The device does not make direct electrical contact with the wearer, nor does it generate or apply electrical stimulation or excitation signals. As such, when used as intended, the TinZr presents minimal inherent electrical risk.
When deployed in wearable or human-adjacent applications, the TinZr is typically powered solely by its onboard battery and communicates wirelessly via BLE or Wi-Fi. This battery-only, wireless mode of operation significantly reduces the risk of electrical shock associated with mains-powered systems.
If the TinZr is connected to external sensors or peripherals that may contact a human subject, it is the user’s responsibility to ensure that those components meet appropriate electrical safety and isolation standards. The TinZr Rev5 has not been tested, certified, or approved for clinical or medical use, and should therefore be used exclusively for research, prototyping, or non-clinical applications unless additional safety certification is obtained.
As with most open-source hardware platforms, the TinZr is provided without warranty, and its use is undertaken at the user’s own risk. The authors disclaim all liability to the extent permitted by applicable law.

### 8. Validation and characterization

To validate the operation and characterize the performance of the TinZr Rev 5 platform, we conducted two complementary test cases. These were designed to evaluate the system across key intended use scenarios, namely, (a) multi-device communication and coordination and (b) real-time sensor data acquisition.

8.1 Multi-Device Communication and Coordination

Multi-device communication and coordination were validated using the TinZrComCenter framework. In this configuration, multiple TinZr devices simultaneously connect to a central host system (a personal computer) that functions as a communication hub. The firmware supports bi-directional communication over TCP/IP, enabling both TinZr-to-hub and hub-to-TinZr messaging, as well as broadcast commands addressed to all connected TinZr units. This test case demonstrates the TinZr platform’s ability to support coordinated, multinode operation, enabling use cases such as distributed sensing, synchronized data acquisition, and swarm-style control architectures. For demonstration purposes, we deployed the Arduino-based firmware located at:

TinZr/libraries/TinZrConnect/examples/TinZrComCenter/TinZrComCenter.ino

First, the user should connect the PC to the same Wi-Fi network to which the TinZrs are intended to connect. In the firmware, the user should provide the Wi-Fi SSID and password, the PC’s IP address, and a hostname for the TinZr onto which the code is flashed. Here, we upload the firmware to two TinZr devices, referred to as

TinZrBlack (black-colored enclosure) and TinZrGold (gold-colored enclosure). Next, we launch the companion Python-based graphical user interface (GUI)²
located at:

TinZr/libraries/TinZrConnect/examples/TinZrComCenter/TinZrComCenter.py

After both devices successfully connected to the hub, a broadcast command was issued to set the onboard RGB LEDs to blue by sending the command LED 0 0 255 20, which specifies red, green, and blue color intensities of 0, 0, and 255, respectively, with a low brightness level of 20. As shown in the left panel of Figure 4,

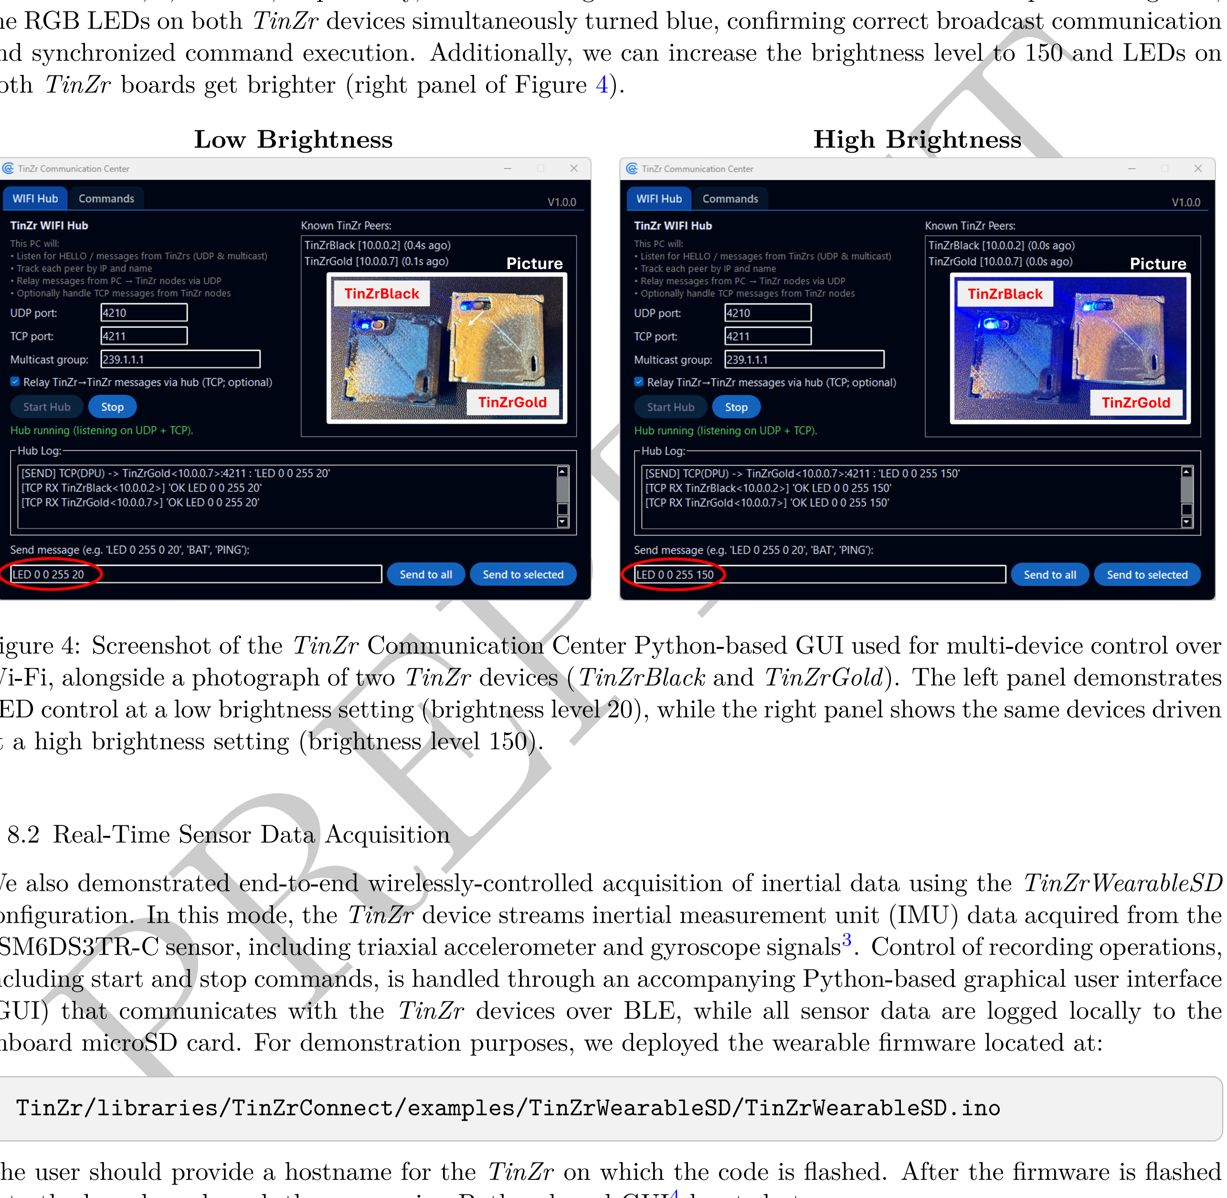
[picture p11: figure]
PREPRINT; Low Brightness; High Brightness; 8.2 Real-Time Sensor Data Acquisition; . Control of recording operations,

the RGB LEDs on both TinZr devices simultaneously turned blue, confirming correct broadcast communication and synchronized command execution. Additionally, we can increase the brightness level to 150 and LEDs on both TinZr boards get brighter (right panel of Figure 4).

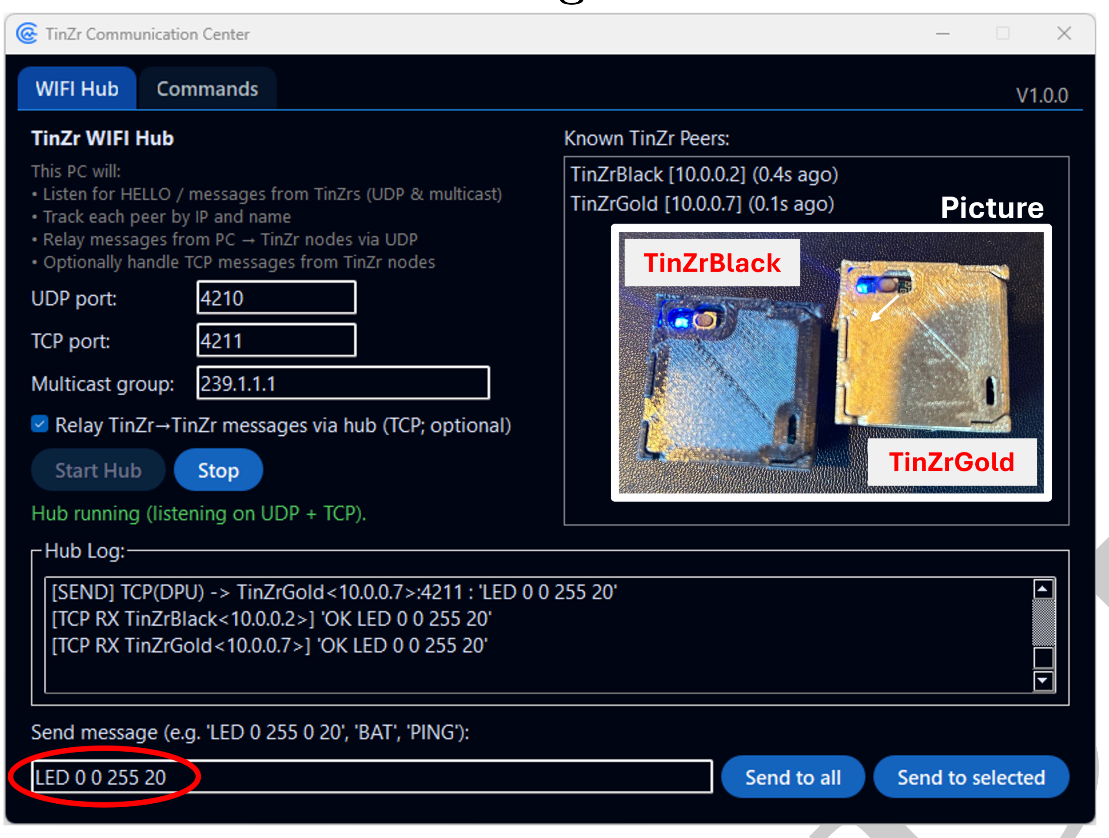
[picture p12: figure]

Figure 4: Screenshot of the TinZr Communication Center Python-based GUI used for multi-device control over Wi-Fi, alongside a photograph of two TinZr devices (TinZrBlack and TinZrGold). The left panel demonstrates LED control at a low brightness setting (brightness level 20), while the right panel shows the same devices driven at a high brightness setting (brightness level 150).

We also demonstrated end-to-end wirelessly-controlled acquisition of inertial data using the TinZrWearableSD configuration. In this mode, the TinZr device streams inertial measurement unit (IMU) data acquired from the LSM6DS3TR-C sensor, including triaxial accelerometer and gyroscope signals³
including start and stop commands, is handled through an accompanying Python-based graphical user interface (GUI) that communicates with the TinZr devices over BLE, while all sensor data are logged locally to the onboard microSD card. For demonstration purposes, we deployed the wearable firmware located at:

TinZr/libraries/TinZrConnect/examples/TinZrWearableSD/TinZrWearableSD.ino

The user should provide a hostname for the TinZr on which the code is flashed. After the firmware is flashed onto the board, we launch the companion Python-based GUI⁴
located at:

2We also provide an executable file that installs the GUI on the PC without the need to run any Python codes. This file is available in the repository under the TinZrComCenter directory and as part of the repository release.
3This firmware also supports the addition of a photoplethysmographic (PPG) sensor, MAX30102, when the optical module is present. The MAX30102 interfaces with the TinZr board via an I²C connection using the onboard QWIIC connector. When no MAX30102 sensor is connected, the corresponding PPG channels are reported as zero-valued signals.
4Similar to the previous example, we also provide an executable file that installs the GUI on the PC without the need to run any Python codes. This file is available in the repository under the TinZrWearableSD directory, and as part of the repository release.

TinZr/libraries/TinZrConnect/examples/TinZrWearableSD/TinZrWearableSD.py

For illustration purposes, we collected IMU data under three conditions and report representative snapshots of the streamed sensor data in Figure 5.

In the first condition, data were collected while the participant sat still while holding the TinZr in the right hand (data reported in the left panel of Figure 5). Next, the data were then collected during repetitive hand up-and-down motion at a frequency of 50 bpm (beats per minute) (middle panel of Figure 5). Finally, the

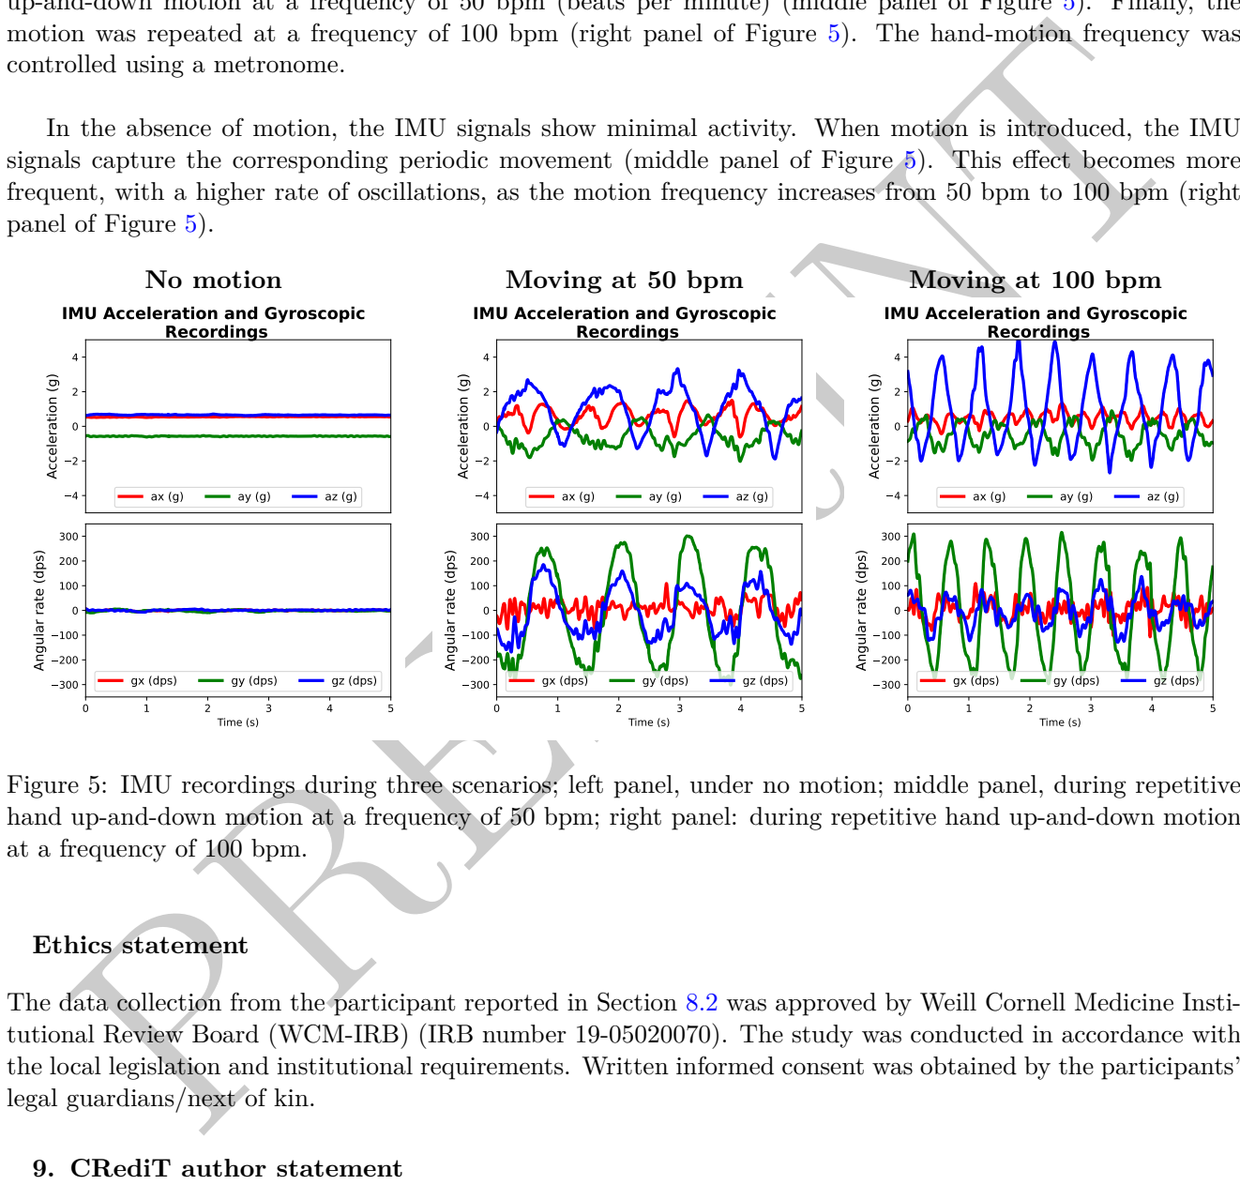
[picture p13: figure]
PREPRINT; controlled using a metronome.; panel of Figure 5).; No motion; Moving at 50 bpm; Moving at 100 bpm; Acceleration (g); Time (s); Angular rate (dps); gx (dps); gy (dps); gz (dps); IMU Acceleration and Gyroscopic Recordings; at a frequency of 100 bpm.; Ethics statement; legal guardians/next of kin.; 9. CRediT author statement

motion was repeated at a frequency of 100 bpm (right panel of Figure 5). The hand-motion frequency was

In the absence of motion, the IMU signals show minimal activity. When motion is introduced, the IMU signals capture the corresponding periodic movement (middle panel of Figure 5). This effect becomes more frequent, with a higher rate of oscillations, as the motion frequency increases from 50 bpm to 100 bpm (right

Figure 5: IMU recordings during three scenarios; left panel, under no motion; middle panel, during repetitive hand up-and-down motion at a frequency of 50 bpm; right panel: during repetitive hand up-and-down motion

The data collection from the participant reported in Section 8.2 was approved by Weill Cornell Medicine Institutional Review Board (WCM-IRB) (IRB number 19-05020070). The study was conducted in accordance with the local legislation and institutional requirements. Written informed consent was obtained by the participants’

Ludvik Alkhoury: Conceptualization, Methodology, Software, Validation, Investigation, Data Curation, Writing - Original Draft, Writing - Review & Editing. Tony Moore: Conceptualization, Resources, Visualization, Writing - Review & Editing. Petras Swissler: Resources, Visualization, Writing - Review & Editing. N. Jeremy Hill: Resources, Visualization, Writing - Review & Editing. Sudhin A. Shah: Resources, Visualization, Writing - Review & Editing. Moshe Kam: Resources, Visualization, Funding Acquisition, Supervision, Writing - Review & Editing.

# PREPRINT

### 10. Declaration of competing interest

Ludvik Alkhoury, N. Jeremy Hill, and Sudhin A. Shah hold equity in and serve as the founding team for Cognitive Signals Inc. These interests have been disclosed to the authors’ respective institutions and are managed in accordance with their conflict-of-interest policies. The remaining authors declare no competing interests.

### 11. Acknowledgements

This work was funded by the New Jersey Institute of Technology (NJIT), Office of the Dean, Newark College of Engineering (NCE). Author N. Jeremy Hill acknowledges support from the NIH (grant P41EB018783), from NY State SCIRB (C37714GG-IDEA and C41212GM-IDEA), and from the Stratton VA Medical Center.

References

[1] Jayraj V. Vaghasiya, Carmen C. Mayorga-Martinez, and Martin Pumera. Wearable sensors for telehealth based on emerging materials and nanoarchitectonics. npj Flexible Electronics, 7(1):26, 2023.
[2] Straits Research. Wearable sensors market size and outlook, 2025–2033. https://straitsresearch.com/report/wearable-sensors-market, (https://straitsresearch.com/report/wearable-sensors-market) 2024. Accessed: 2025-10-12.
[3] Bradley J. Petek, Mostafa A. Al-Alusi, Nathaniel Moulson, Aubrey J. Grant, Cyril Besson, J. Sawalla Guseh, Meagan M. Wasfy, Vincent Gremeaux, Timothy W. Churchill, and Aaron L. Baggish. Consumer wearable health and fitness technology in cardiovascular medicine: JACC state-of-the-art review. Journal of the American College of Cardiology, 82(3):245–264, 2023.
[4] Dhruv R. Seshadri, Ryan T. Li, James E. Voos, James R. Rowbottom, Celeste M. Alfes, Christian A. Zorman, and Colin K. Drummond. Wearable sensors for monitoring the internal and external workload of the athlete. npj Digital Medicine, 2(1):71, 2019.
[5] Rory A. Cooper, George Smolinski, Jorge L. Candiotti, Shantanu Satpute, Garrett G. Grindle, Tawnee L. Sparling, Michelle J. Nordstrom, Xiaoning Yuan, Allison Symsack, Chang Dae Lee, et al. Current state, needs, and opportunities for wearable robots in military medical rehabilitation and force protection. In Actuators, volume 13, page 236. MDPI, 2024.
[6] Patrik Kutilek, Petr Volf, Slavka Viteckova, Pavel Smrcka, Vaclav Krivanek, Lenka Lhotska, Karel Hana, Radek Doskocil, Leos Navratil, Zdenek Hon, et al. Wearable systems for monitoring the health condition of soldiers: Review and application. In Proceedings of the International Conference on Military Technologies (ICMT), pages 748–752. IEEE, 2017.
[7] Che-Chang Yang and Yeh-Liang Hsu. A review of accelerometry-based wearable motion detectors for physical activity monitoring. Sensors, 10(8):7772–7788, 2010.
[8] Ludvik Alkhoury, JiWon Choi, Vishnu D. Chandran, Gabriela B. de Carvalho, Saikat Pal, and Moshe Kam. Dual-wavelength photoplethysmography framework for heart rate calculation. Sensors, 22(24):9955, 2022.
[9] Ludvik Alkhoury, Ji-Won Choi, Chizhong Wang, Arjun Rajasekar, Sayandeep Acharya, Sean Mahoney, Barry S. Shender, Leonid Hrebien, and Moshe Kam. Heart-rate tuned comb filters for processing photoplethysmogram (PPG) signals in pulse oximetry. Journal of Clinical Monitoring and Computing, 35(4):797– 813, 2021.
[10] Mohamed Adel Serhani, Hadeel T. El Kassabi, Heba Ismail, and Alramzana Nujum Navaz. ECG monitoring systems: Review, architecture, processes, and key challenges. Sensors, 20(6):1796, 2020.

# PREPRINT (https://www.adafruit.com/product/1222)

[11] Burcu Arman Kuzubasoglu, Ersin Sayar, Cedric Cochrane, Vladan Koncar, and Senem Kursun Bahadir. Wearable temperature sensor for human body temperature detection. Journal of Materials Science: Materials in Electronics, 32(4):4784–4797, 2021.
[12] Ziao Xue, YanSong Gai, Yuxiang Wu, Zhuo Liu, and Zhou Li. Wearable mechanical and electrochemical sensors for real-time health monitoring. Communications Materials, 5(1):211, 2024.
[13] Rahul K. Kher and Dipak M. Patel. A comprehensive review on wearable health monitoring systems. The Open Biomedical Engineering Journal, 15(1), 2021.
[14] Louis J. Dankovich, Janell S. Joyner, William He, Ahmad Sesay, and Monifa Vaughn-Cooke. CogWatch: An open-source platform to monitor physiological indicators for cognitive workload and stress. HardwareX, 19, 2024.
[15] Adafruit Industries LLC. Adafruit QT Py ESP32-S2 WiFi dev board (product id: 5325). https://www.adafruit.com/product/5325, 2022. Accessed: 2025-10-13.
[16] Tommaso Polonelli, Lukas Schulthess, Philipp Mayer, Michele Magno, and Luca Benini. H-Watch: An open, connected platform for AI-enhanced COVID-19 symptom monitoring and contact tracing. In Proceedings of the IEEE International Symposium on Circuits and Systems (ISCAS), pages 1–5. IEEE, 2021.
[17] Sebastian Frey, Giusy Spacone, Andrea Cossettini, Marco Guermandi, Philipp Schilk, Luca Benini, and Victor Kartsch. BioGAP-Ultra: A modular edge-AI platform for wearable multimodal biosignal acquisition and processing. arXiv preprint arXiv:2508.13728, 2025.
[18] Gabriel P. M. Pinheiro, Ricardo K. Miranda, Bruno J. G. Praciano, Giovanni A. Santos, F´abio L. L. Mendon¸ca, Elnaz Javidi, Jo˜ao Paulo da Costa, and Jr. de Sousa, Rafael T. Multi-sensor wearable health device framework for real-time monitoring of elderly patients using a mobile application and high-resolution parameter estimation. Frontiers in Human Neuroscience, 15:750591, 2022.
[19] Texas Instruments. CC2640R2F SimpleLink Bluetooth Low Energy wireless MCU. https://www.ti.com/product/CC2640R2F, (https://www.ti.com/product/CC2640R2F) 2020. Accessed: 2025-10-13.
[20] Seeed Studio. Getting started with Seeed Studio XIAO ESP32C3. https://wiki.seeedstudio.com/XIAO ESP32C3 Getting Started/, (https://wiki.seeedstudio.com/XIAO_ESP32C3_Getting_Started/) 2024. Accessed: 2025-10-13.
[21] Amazon. | ESP32-C3 | mini | development | board. | https://www.amazon.com/
ESP32-C3-Development-Bluetooth-Single-Core-Processor/dp/B0D5XNBPBC?th=1, (https://www.amazon.com/ESP32-C3-Development-Bluetooth-Single-Core-Processor/dp/B0D5XNBPBC?th=1) 2025. | Accessed:
2025-10-13.
[22] DFRobot. Beetle ESP32-C6 mini development board. https://www.dfrobot.com/product-2778.html, 2025. Accessed: 2025-10-13.
[23] Adafruit Industries LLC. GEMMA v2 — miniature wearable electronic platform (product id: 1222). https://www.adafruit.com/product/1222, 2025. Accessed: 2025-10-13.
[24] PJRC. Teensy 4.1 development board. https://www.pjrc.com/store/teensy41.html, 2025. Accessed: 2025-10-13.
[25] EasyEDA Team. EasyEDA: Online PCB design tool. https://easyeda.com/, 2024. Accessed: 2024-08-13.
[26] KiCad Development Team. Kicad EDA. https://www.kicad.org/, 2024. Accessed: 2024-08-15.
[27] FreeCAD Community. FreeCAD: Your own 3d parametric modeler. https://www.freecad.org/, 2024. Accessed: 2024-08-15.
[28] Adafruit Industries LLC. Lithium ion polymer battery — 3.7V 150mAh (product id: 1317). https: //www.adafruit.com/product/1317. Accessed: 2026-01-12.

# PREPRINT

[29] AEDIKO. | MAX30102 | heart | rate | sensor | module | (2-pack). | https://www.amazon.com/
AEDIKO-MAX30102-Detection-Concentration-Compatible/dp/B09LQDW27N, (https://www.amazon.com/AEDIKO-MAX30102-Detection-Concentration-Compatible/dp/B09LQDW27N) 2026. Accessed: 2026-01-12.

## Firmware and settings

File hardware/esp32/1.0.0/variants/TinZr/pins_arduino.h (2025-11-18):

#ifndef Pins_Arduino_h
#define Pins_Arduino_h

#include <stdint.h>
#include "soc/soc_caps.h"

// ===== Built-in RGB on GPIO8 =====
#define PIN_RGB_LED 8
#define PB_PIN 9

// Use a "virtual" builtin index so rgbLedWrite() works (not digitalWrite)
static const uint8_t LED_BUILTIN = SOC_GPIO_PIN_COUNT + PIN_RGB_LED;
#define BUILTIN_LED  LED_BUILTIN
#define RGB_BUILTIN  LED_BUILTIN
#define RGB_BRIGHTNESS 128   // 0–255 default

// ===== UART0 defaults (USB-CDC) =====
static const uint8_t TX = 21;
static const uint8_t RX = 20;

// ===== I2C defaults (avoid strap pins 8/9) =====
static const uint8_t SDA = 4;
static const uint8_t SCL = 5;
#define PIN_WIRE_SDA SDA
#define PIN_WIRE_SCL SCL

// ===== SPI defaults =====
static const uint8_t SS   = 10;
static const uint8_t MOSI = 2;
static const uint8_t MISO = 7;
static const uint8_t SCK  = 6;
#define PIN_SPI_SS   SS
#define PIN_SPI_MOSI MOSI
#define PIN_SPI_MISO MISO
#define PIN_SPI_SCK  SCK

// ===== Analog aliases (C3: ADC1=GPIO0..4, ADC2=GPIO5) =====
static const uint8_t A0 = 0;
static const uint8_t A1 = 1;
static const uint8_t A2 = 2;
static const uint8_t A3 = 255; // not available on this board
static const uint8_t A4 = 4;
static const uint8_t A5 = 5;   // ADC2; OK but has caveats vs ADC1

#endif /* Pins_Arduino_h */

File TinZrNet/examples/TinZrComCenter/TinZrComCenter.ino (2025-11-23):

#include <Arduino.h>
#include "TinZrNode.h"  

TinZrNode Node;

TinZrNodeConfig cfg = {
  .console = {
    .ssid       = "connect123",
    .pass       = "connect123",
    .hostname   = "TinZrNode1",  // or nullptr to reuse saved hostname
    .use_static = false
  },
  .hubTcpPort  = 4211,
  .hubUdpPort  = 4210,
  .hubMcastGrp = IPAddress(239, 1, 1, 1),
  .hubIP       = IPAddress(172, 20, 10, 4),  // PC IP
};

void setup() {
  Node.begin(cfg);
}

void loop() {
  Node.handle();
  
}

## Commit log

2025-10-23 created zip! Ready for release.
    [app3M_fat9M_16MB.csv, app3M_fat9M_fact512k_16MB.csv, app3M_spiffs9M_fact512k_16MB.csv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]
2025-10-23 Added main menu for the tools in Arduino
2025-10-23 updated the boards info and created new zip
2025-10-27 Made some modifications to the GUI to modify the RGB LED on the board and show IMU and PPG data. Next I will add saving functionalities.
2025-11-29 Added a hub for wearables with PPG accelerometers and gyros.
2025-11-30 First attempt of a nice GUI for wearable Red IR Acc and Gyro collection.
2025-11-30 Wearable GUI can now show battery level HR and SpO2.
2025-12-01 Acc and gyros do not saturate now.
2025-12-03 Added a 3D design for the wearable TinZr. Also for the BLE and WIFI hub, each ino code has its own config.h to set up BLE, WIFI, and OTA (only with WIFI).
    [TinZrWearableEnclosure.FCStd]
2025-12-10 Renamed enclosure.
    [TinZrWearableEnclosure-Bottom.stl, TinZrWearableEnclosure-Top.stl, TinZrWearableEnclosure.FCStd]
2025-12-17 Update README for TinZr ESP32-C3 package
2025-12-18 For the wearable example, if the PPG sensor is not attached, then we will send zeros.
2025-12-19 first attempt at a multi wearable recording
    [TinZrBlack_D885AC4E386E.csv]
2025-12-19 Multi wearable is a separate example now.
    [TinZrBlack_D885AC4E386E.csv]
2025-12-30 Updated 3D enclosure
    [TinZrWearableEnclosure.FCStd]
2025-12-31 Added rendering files
    [TinZrWearableEnclosure_ToRender.FCStd]
2026-01-14 WearableSD can now wireless transfer the saved data files from the TinZr to the PC.
2026-01-19 V1.0.0 for the wearable and communication center GUI .exe installers.
    [TinZrWearableEnclosure-BatLid.stl, TinZrWearableEnclosure-Button.stl, TinZrWearableEnclosure.FCStd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]
2026-01-19 added battery reading in the web app.
2026-01-22 Update README with board installation instructions
2026-03-27 Added a warning note for TinZrWearableSD in case more than 1 TinZr device is used. In this case, de-synchronization and drifts could happen since the TinZrs have different clocks. In the case of mult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
2026-04-22 PPG reading is now in nA instead of the ADC value. Also there is an attempt to make the TinZrWearableSD `now called TinZrWearableSD_` smoother where ONLY the start data logging happends over BLE to r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
2026-05-03 Added newer enclosure model.
    [TinZrWearableEnclosure - Body.step, TinZrWearableEnclosure - Body.stl, TinZrWearableEnclosure - Lid.step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]
2026-06-08 Added a TinZrWearable for wireless (BLE) communication for IMU and PPG data. This is still not tested well, especially for dropping data points during transfer.
2026-07-24 Fixed a bug in the logging where the sensors were logging slower than SD logging.
